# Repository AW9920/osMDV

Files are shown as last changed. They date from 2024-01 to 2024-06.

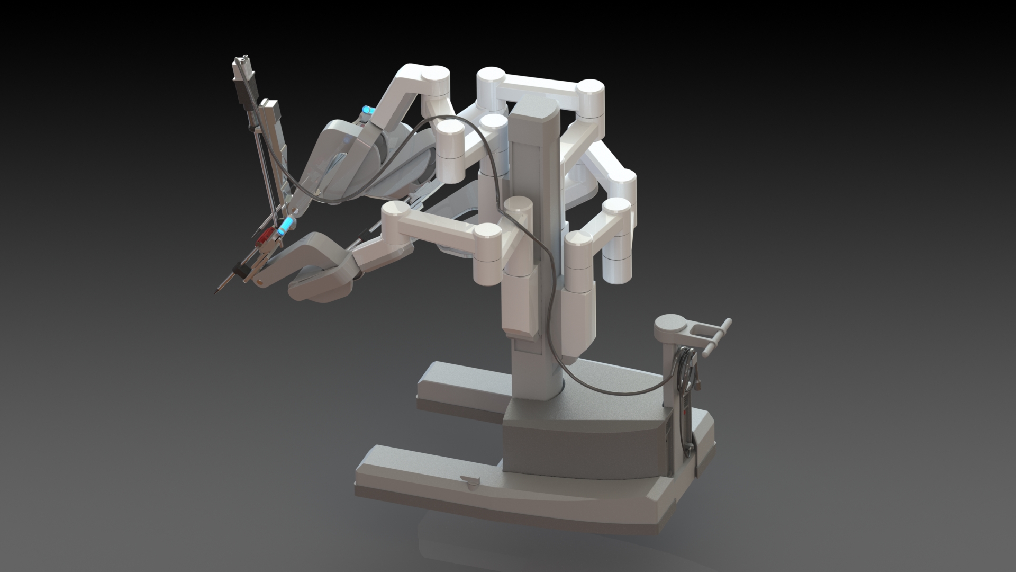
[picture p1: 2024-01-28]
CAD-PSM/Ueberarbeiteter DaVincikopf/da-vinci-surgical-robot-1.snapshot.1/DaVinci/Render/3.JPG

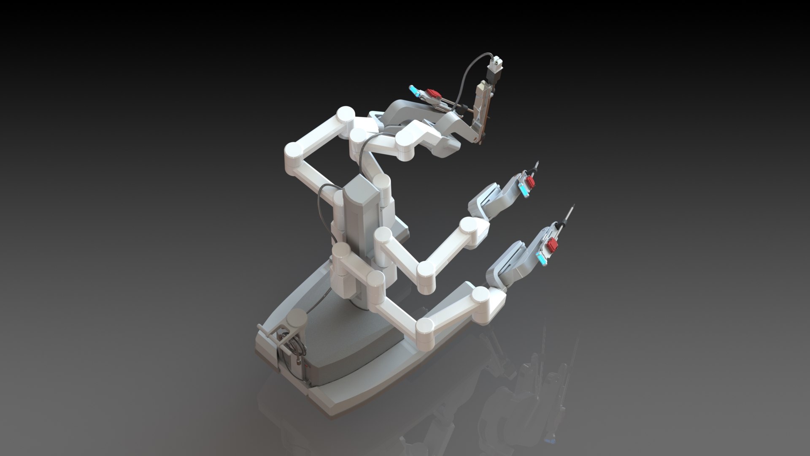
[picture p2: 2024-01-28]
CAD-PSM/Ueberarbeiteter DaVincikopf/da-vinci-surgical-robot-1.snapshot.1/DaVinci/Render/9.JPG

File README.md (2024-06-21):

# Open-Source Desktop Teleoperated Surgical Training System


Welcome to the repository for the **Open-Source Desktop Teleoperated Surgical Training System**. This project provides cost-efficient and accessible resources for a surgical training system.

## Features

- **Master-Tool-Manipulator (MTM)**: A serial link manipulator capable of measuring the operator’s motion in 7 degrees of freedom (DoF), including 3 DoF for hand translation, 3 DoF for wrist rotation, and 1 DoF for grasping motion.
- **Patient-Side-Manipulator (PSM)**: Based on the da Vinci Classic system, this manipulator features a double parallelogram mechanism and is capable of precise motion replication.
- **Kinematic Models**: Detailed kinematic models for both MTM and PSM using the Denavit-Hartenberg (DH) method.
- **Gravity-Compensation-System (GCS)**: Simulated spatial positions of the center of gravity for counterbalancing mechanisms, designed using a least-square fitting algorithm.

## Repository Contents

- **CAD Drawings**: Detailed CAD drawings for the MTM and PSM, including all necessary components and assembly instructions.
- **Source Code**: Control algorithms, kinematic models, and simulation scripts necessary for operating the MTM and PSM.
- **Calculations**: Documentation of the kinematic and dynamic calculations used in the system design.

## License
This project is licensed under the MIT License. See the LICENSE file for more details.

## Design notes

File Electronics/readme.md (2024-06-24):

# Electronics MTM

## General Description of the Electrical Setup MTM
The robotic arm system incorporates sensors and controllers to detect movements and control various joints. Each side of the arm is equipped with sensors for shoulder pitch, shoulder yaw, elbow pitch, wrist, and grip, all centrally controlled by an Arduino Mega.

### Shoulder Pitch Subsystem:
- **Magnetic Encoder (AEAT-6012-A06)**: Provides precise feedback on the shoulder pitch position.

### Shoulder Yaw Subsystem:
- **Magnetic Encoder (AEAT-6012-A06)**: Measures the shoulder yaw angle accurately.

### Elbow Pitch Subsystem:
- **Magnetic Encoder (AEAT-6012-A06)**: Monitors the elbow pitch movement.

### Wrist Subsystem:
- **MPU 6050**: Tracks the wrist orientation and movement. The MPU measures 3 degrees of freedom.

### Grip Subsystem:
- **Hall Sensor**: Detects the grip force or position. The location of the measurement is the grip between index finger and thumb.

### Controller
- **Arduino Mega**: The central controller orchestrates the operations of all subsystems. It processes input signals from the encoders, MPU 6050 sensors, and Hall sensors and sends appropriate control signals to achieve coordinated and precise movements of the robotic arm.

## Electrical Schematic MTM




# Electronics PSM

## General Description of the Electrical Setup
The MTM detects movements in 7 dimensions of freedom. Consequently, the PSM requires 7 motors to replicate these movements. Servo motors, which have integrated position control, are utilized for wrist movements. For the outer yaw, pitch, and insertion, DC motors are employed, and these motors need additional encoders for position control. To calibrate the encoders, the PSM uses limit switches to detect the end positions.

The electrical system of the project is composed of three main subsystems: outer pitch, outer yaw, and insertion. Each subsystem is managed by a central controller, the Teensy 4.1, which interfaces with various sensors, motors, and motor drivers to ensure precise and coordinated movement.

### Outer Pitch Subsystem
- **Limit Switch**: An Omron D2F-L-A1 limit switch is used to detect the end-of-travel positions for safety and calibration purposes.
- **Encoder**: A Broadcom HEDS-5540 encoder provides feedback on the rotational position and speed of the DC motor.
- **DC Motor**: A Maxon 273752 15V DC motor is responsible for generating the necessary torque and motion.
- **Motor Driver**: An MD13S Cytron 13 Amp motor driver controls the power supplied to the DC motor based on commands from the controller.

### Outer Yaw Subsystem
- **Limit Switch**: Another Omron D2F-L-A1 limit switch is employed to detect the limits of travel.
- **Encoder**: The Broadcom HEDS-5540 encoder offers precise feedback on the motor's position and velocity.
- **DC Motor**: A similar Maxon 273752 15V DC motor is used for the yaw movement.
- **Motor Driver**: The MD13S Cytron 13 Amp motor driver modulates the power delivered to the DC motor.

### Insertion Subsystem
- **Limit Switch**: The Omron D2F-L-A1 limit switch is utilized for detecting the extreme positions.
- **Encoder**: The Broadcom HEDS-5540 encoder measures the rotational position for precise control.
- **Servo Motor**: A servo motor (HV7346MG) with position control removed is used to drive the insertion mechanism.
- **Motor Driver**: The same MD13S Cytron 13 Amp motor driver is used to control the servo motor.

### Wrist Subsystem
The wrist subsystem comprises multiple servo motors (MG966r) for fine-tuned multi-axis control. These servos are directly controlled by the Teensy 4.1 controller to achieve the desired movements.

### Controller
- **Teensy 4.1**: The central controller that orchestrates the operations of all subsystems. It processes input signals from encoders and limit switches and sends appropriate control signals to the motor drivers and servo motors.



## Electrical Schematic PSM







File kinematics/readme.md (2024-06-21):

# Kinematic Model - MTM

MTM_Kinematics_v2

## **DH-Parameters of the MTM**

| i | theta_i / rad | d_i / mm | a_i / mm | alpha_i / rad |
|---|---|---|---|---|
| 1 | q_1 | 0 | l_sho | pi/2 |
| 2 | q_2 | 0 | l_arm | -pi/2 |
| 3 | q_3 - pi/2 | -l_ball  | l_arm | -pi/2 |
| 4 | q_4 - pi/2 | 0 | 0 | -pi/2 |
| 5 | q_5 - pi/2 | 0 | 0 | -pi/2 |
| 6 | q_6 + pi/2 | -l_IMU | 0 | -pi/2 |

With geometric parameters being:
l_arm = 217.50 mm
l_ball = 8.70 mm
l_IMU = 37.40 mm

# Kinematic Model - PSM

PSM_Kinematics_v2

##  **DH-Parameters of the PSM**

| i | theta_i / rad |  d_i / mm | a_i / mm | alpha_i / rad |
|---|---|---|---|---|
| 1 | q_1 | 0 | 0 | -pi/2 |
| 2 | q_2 - pi/2 | 0 | 0 | pi/2 |
| 3 | 0 | q_3 - l_RCM | 0 | 0 |
| | 0 | l_tool | 0 | 0 |
| 4 | q_4 | 0 | 0 | -pi/2 |
| 5 | q_5 - pi/2 | 0 | l_P2Y | -pi/2 |
| 6 | q_6 | 0 | l_Y2T | 0 |

With geometric parameters being:
l_RCM   = 456.00 mm
l_P2Y   = 9.00 mm
l_tool  = 432.50 mm
l_Y2T   = 10.10 mm

# Inverse Kinematics Wrist Rotation

The analytical form of 3R6 is derived from the DH parameters of the PSM, whereas the elements of the matrix depicted in
the second equation poses numerical values resulting from the transformation of IMU values in Rotation Matrix form (0R6).

### Matrices

$$
^3R_6 = \begin{bmatrix}
-c_4 c_6 - s_4 s_5 s_6 & -s_4 c_5 & c_4 s_6 + s_4 s_5 c_6 \\
s_4 c_6 + c_4 s_5 s_6 & c_4 c_5 & s_4 s_6 + c_4 s_5 c_6 \\
-c_5 s_6 & s_5 & -c_5 c_6
\end{bmatrix}
$$

$$
^0R_3^{-1} \cdot ^0R_6 = \begin{bmatrix}
r_{11} & r_{12} & r_{13} \\
r_{21} & r_{22} & r_{23} \\
r_{31} & r_{32} & r_{33}
\end{bmatrix}
$$

Based on the detailed notation, it is determined that joint values q4, q5, and q6 can be estimated according to the equations listed below.

$$
 q_4 = \arctan2\left(-\frac{r_{12}}{c_5}, \frac{r_{22}}{c_5}\right) 
$$

$$
q_5 = \arctan2\left(r_{32}, \pm\sqrt{(r_{12})^2 + (r_{22})^2}\right) 
$$

$$
q_6 = \arctan2\left(-\frac{r_{31}}{c_5}, -\frac{r_{33}}{c_5}\right) 
$$

# Interpretation of Disk Rotation

The discs of the surgical instrument must be actuated properly to authentically recreate the previously calculated joint values

##  Correlation Matrix
The transmission rate between the disc number and corresponding joint values are estimated and listed below.





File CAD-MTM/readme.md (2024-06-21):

# CAD of the Master Tool Manipulator

This folder provides mechanical assembly and CAD drawings.

## Overview

This section of the repository focuses on the mechanical aspects of the teleoperated surgical training system, including the Master-Tool-Manipulator (MTM). These components are designed to be affordable and easy to assemble, reducing the entry barrier for research and educational purposes.

## Mechanical Assemblies

The MTM is a serial link manipulator designed to measure the operator's motion in 7 degrees of freedom (DoF), including:

- 3 DoF for hand translation
- 3 DoF for wrist rotation
- 1 DoF for grasping motion

**Components:**

- **Frame**: The main structure supporting the MTM.
- **Joints**: Seven joints allowing for the specified degrees of freedom.
- **Encoders**: Three absolute magnetic encoders (AEAT-6012-A06, Broadcom) for measuring hand translation.
- **IMU**: A 6-axis inertial measurement unit encased in a wrist control unit (WCU) for wrist rotation estimation.
- **Hall Sensor**: A sensor (SS495A1, Honeywell) for grasping motion detection.

Revised_MTM_v2

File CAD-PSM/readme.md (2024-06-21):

# CAD of Patient Side Manipulator

This folder provides mechanical assembly and CAD drawings of the PSM.

## Overview

This section of the repository focuses on the mechanical aspects of the teleoperated surgical training system, including the PSM. These components are designed to be affordable and easy to assemble, reducing the entry barrier for research and educational purposes.
The PSM is based on the DaVinci Classic system and features a double parallelogram mechanism for precise motion replication.

**Components:**

- **Frame**: The main supporting structure for the PSM.
- **Joints**: Seven joints, actuated by DC motors (273752, MAXON).
- **Servo Motors**: Four servo motors (HS-65HB+, Hitec) for wrist movements.
- **Optical Encoders**: Encoders (HEDS-5540#A11, Broadcom) for angular position measurement.
- **Surgical Instrument Mount**: A sled to accommodate surgical instruments.

**DPM Base**
ForkMecha
**DPM**
DPM_v2
**Base Shaft**
AX0_new
**Head Assembly**
Guidance
**Tool Carriage**
Carriage_v2

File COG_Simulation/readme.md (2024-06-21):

# COG Simulation
This section provides MATLAB files to calculate the center of gravity of the PSM and MTM throughout their workspace
## COG Calculation MTM

Based on the following mechanical schematic, the position of the MTM's COG is computed as a function of its joint values q1 to q3  



The COG of each link as a function of its corresponding joint values is given below  

COG locations as function of joint values  

## COG Calculation PSM

The positions of the PSM's COGs are computed as a function of its corresponding joint values  



This COG of each of the 6 links of the PSM are computed as listed below  



The simulation of the total COG of MTM and PSM respectively is based on these considerations.

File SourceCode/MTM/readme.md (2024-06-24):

# General Functionality MTM
For both MTMs of the training console, the program is required to read the data from a total of six absolute magnetic encoders, two IMUs and two Hall effect sensors. Whereas, for the received data, a distinction must be made between the movement data of the left and right arm. This results in a total of eight sensor values received per MTM which must be communicated to the computer I/O where they are processed into appropriate joint values for the PSM. 

## MT_MTM.ino
The main control file for the MTM system.
- Integrating all subsystems and coordinating their operations.
- Handling communication with the central controller (Arduino Mega).
- Managing the overall workflow of the MTM system.

### spikeDetection.ino
This file handles the detection of spikes in the movement data, which might indicate rapid or sudden movements. Key functionalities include:
- Variables to store previous and current IMU (Inertial Measurement Unit) readings.
- Spike detection logic to identify abrupt changes in movement.
- Implementation of counters and difference calculations to process the movement data.

### Initial_preVal_def.ino
This file initializes various variables and sets up default values for the system. Key functionalities include:
- Defining initial positions and orientations for the robot.
- Setting up initial encoder values and IMU addresses.
- Initializing kinematic variables for both MTM and PSM.

### KinematicCalc_L.ino and KinematicCalc_R.ino
These files perform kinematic calculations for the left and right sides of the robot, respectively. Key functionalities include:
- Calculating joint angles and positions based on encoder and IMU data.
- Updating the kinematic chain for the MTM to ensure accurate movement detection.

### LPFilter.ino and LPFilter_Encoder.ino
These files implement low-pass filters to smooth the data received from the sensors. Key functionalities include:
- Filtering IMU data to remove noise and ensure smooth movement detection.
- Filtering encoder data to ensure accurate position readings.

### readEncoder.ino
This file contains the code to read data from the encoders. Key functionalities include:
- Reading the position data from the encoders connected to the robot joints.
- Processing the encoder signals to extract meaningful position information.

### OverFlowDetection.ino
This file handles the detection of overflow conditions in the sensor data. Key functionalities include:
- Monitoring sensor values to detect overflows.
- Implementing corrective actions to handle overflow conditions and ensure continuous operation.

### readIMU.ino
This file contains the code to read data from the IMUs. Key functionalities include:
- Reading quaternion data from the IMUs to determine the orientation of the robot.
- Handling FIFO (First In, First Out) buffers to manage IMU data efficiently.

### setupIMU.ino
This file sets up the IMUs (Inertial Measurement Units) for use in the MTM system. Key functionalities include:
- Initializing IMU sensors.
- Configuring IMU settings and calibration parameters.
- Ensuring the IMUs are ready for accurate orientation tracking.

### parseData.ino
This file contains the logic to parse incoming data strings. Key functionalities include:
- Tokenizing received data strings.
- Converting tokenized strings into numerical values.
- Storing parsed data into appropriate variables for further processing.

### recvWithStartEndMarkers.ino
This file implements the functionality to receive data with defined start and end markers. Key functionalities include:
- Detecting start and end markers in incoming serial data.
- Extracting and storing data between the markers.
- Setting flags to indicate new data availability for processing.

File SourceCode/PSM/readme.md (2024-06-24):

# General Functionality
The PSM code is designed to accurately replicate the movements detected by the MTM. It does so by receiving movement data from the MTM, parsing and processing this data, and then using it to control the PSM's motors and servos. The system uses PID control to ensure precise movements and implements various safety and efficiency measures such as ramp-up routines, collision detection, and low-pass filtering.

## MT_PSM.ino
This is the main control file for the PSM system. Key functionalities include:
- Initializing the PSM components and setting up initial configurations.
- Reading data from the MTM and converting it into commands for the PSM.
- Handling the overall workflow (see the following picture) of the PSM to ensure it accurately replicates MTM movements.

  

## parseData.ino
This file contains the logic to parse incoming data strings from the MTM. Key functionalities include:
- Tokenizing received data strings.
- Converting tokenized strings into numerical values.
- Storing parsed data into appropriate variables for further processing.

## PIDupdate.ino
This file implements PID (Proportional-Integral-Derivative) control for the motors. Key functionalities include:
- Calculating PID values to control motor speed and position.
- Adjusting motor commands based on the PID calculations to ensure precise movements.

## PosSampler.ino
This file handles the sampling of position data. Key functionalities include:
- Reading position data from sensors.
- Storing sampled data for use in control algorithms.
- Ensuring that position data is accurately and consistently captured.

## RampUp_Homing.ino
This file implements ramp-up and homing routines for the PSM. Key functionalities include:
- Performing homing sequences to establish a known starting position for the PSM.

## recvWithStartEndMarkers.ino
This file handles the reception of data with defined start and end markers. Key functionalities include:
- Detecting start and end markers in incoming serial data.
- Extracting and storing data between the markers.
- Setting flags to indicate new data availability for processing.

## setPwmFrequency.ino
This file sets the PWM (Pulse Width Modulation) frequency for the motors. Key functionalities include:
- Configuring PWM settings for motor control.
- Ensuring that motors operate at the correct frequency for smooth and precise movements.

## Catch_Tool.ino
This file contains routines to catch and manipulate tools. Key functionalities include:
- Controlling servos to grip the tool securely.
- Returning to the initial position after catching the tool.

## CheckCol.ino
This file checks for collision conditions during operation. Key functionalities include:
- Monitoring limit switches to detect collisions.
- Stopping motors if a collision is detected to prevent damage.
- Ensuring safe operation by avoiding excessive forces.

## LPFilter_DT.ino
This file implements a low-pass filter for delta time signals. Key functionalities include:
- Filtering delta time measurements to remove noise.
- Ensuring stable and accurate time measurements for control algorithms.

# Referencing
Since incremental encoders are utilized for joint axis 1, 2, and 3, the system must conduct a reference drive before it is ready for operation. This is necessary since the encoders do not possess an absolute point of reference, which causes a loss of position whenever the program execution is terminated. Therefore, a state machine is implemented to guide each joint towards a limit switch positioned at a specific angle. Since the encoders of the remaining joints are able to measure the absolute position at any time, they are excluded from the reference drive procedure. The protocol of the state machine is visualized by the flow chart in Figure.



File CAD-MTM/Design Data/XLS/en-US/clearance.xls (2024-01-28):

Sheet: Ansi Unified Screw Threads
I | Sort Order -1
Fastener Type | Size | Shaft Diameters |  |  | Head Dimensions
 |  | Close | Normal | Loose | Diameter | Depth/Angle | Head Type
Flat Head Machine Screw (82) | #0 | 0.0635 | 0.07 | 0.073 | 0.119 | 82 | 2
Flat Head Machine Screw (82) | #1 | 0.076 | 0.081 | 0.089 | 0.146 | 82 | 2
Flat Head Machine Screw (82) | #2 | 0.089 | 0.096 | 0.1065 | 0.172 | 82 | 2
Flat Head Machine Screw (82) | #3 | 0.104 | 0.11 | 0.12 | 0.199 | 82 | 2
Flat Head Machine Screw (82) | #4 | 0.116 | 0.1285 | 0.136 | 0.225 | 82 | 2
Flat Head Machine Screw (82) | #5 | 0.1285 | 0.136 | 0.154 | 0.252 | 82 | 2
Flat Head Machine Screw (82) | #6 | 0.144 | 0.1495 | 0.1695 | 0.279 | 82 | 2
Flat Head Machine Screw (82) | #8 | 0.1695 | 0.177 | 0.1935 | 0.332 | 82 | 2
Flat Head Machine Screw (82) | #10 | 0.196 | 0.201 | 0.221 | 0.385 | 82 | 2
Flat Head Machine Screw (82) | #12 | 0.221 | 0.228 | 0.246 | 0.438 | 82 | 2
Flat Head Machine Screw (82) | 1/4 | 0.257 | 0.266 | 0.2812 | 0.507 | 82 | 2
Flat Head Machine Screw (82) | 5/16 | 0.323 | 0.332 | 0.3437 | 0.635 | 82 | 2
Flat Head Machine Screw (82) | 3/8 | 0.386 | 0.397 | 0.4062 | 0.762 | 82 | 2
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

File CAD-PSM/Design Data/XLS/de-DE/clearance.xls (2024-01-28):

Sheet: ANSI UST
I | Reihenfolge -1
Schraubentyp | Größe | Wellendurchmesser |  |  | Schraubenkopfbemaßungen
 |  | Schließen | Normal | Grob | Durchmesser | Tiefe/Winkel | Schraubenkopftyp
Flachkopfmaschinenschraube (82) | #0 | 0.0635 | 0.07 | 0.073 | 0.119 | 82 | 2
Flachkopfmaschinenschraube (82) | #1 | 0.076 | 0.081 | 0.089 | 0.146 | 82 | 2
Flachkopfmaschinenschraube (82) | #2 | 0.089 | 0.096 | 0.1065 | 0.172 | 82 | 2
Flachkopfmaschinenschraube (82) | #3 | 0.104 | 0.11 | 0.12 | 0.199 | 82 | 2
Flachkopfmaschinenschraube (82) | #4 | 0.116 | 0.1285 | 0.136 | 0.225 | 82 | 2
Flachkopfmaschinenschraube (82) | #5 | 0.1285 | 0.136 | 0.154 | 0.252 | 82 | 2
Flachkopfmaschinenschraube (82) | #6 | 0.144 | 0.1495 | 0.1695 | 0.279 | 82 | 2
Flachkopfmaschinenschraube (82) | #8 | 0.1695 | 0.177 | 0.1935 | 0.332 | 82 | 2
Flachkopfmaschinenschraube (82) | #10 | 0.196 | 0.201 | 0.221 | 0.385 | 82 | 2
Flachkopfmaschinenschraube (82) | #12 | 0.221 | 0.228 | 0.246 | 0.438 | 82 | 2
Flachkopfmaschinenschraube (82) | 1/4 | 0.257 | 0.266 | 0.2812 | 0.507 | 82 | 2
Flachkopfmaschinenschraube (82) | 5/16 | 0.323 | 0.332 | 0.3437 | 0.635 | 82 | 2
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

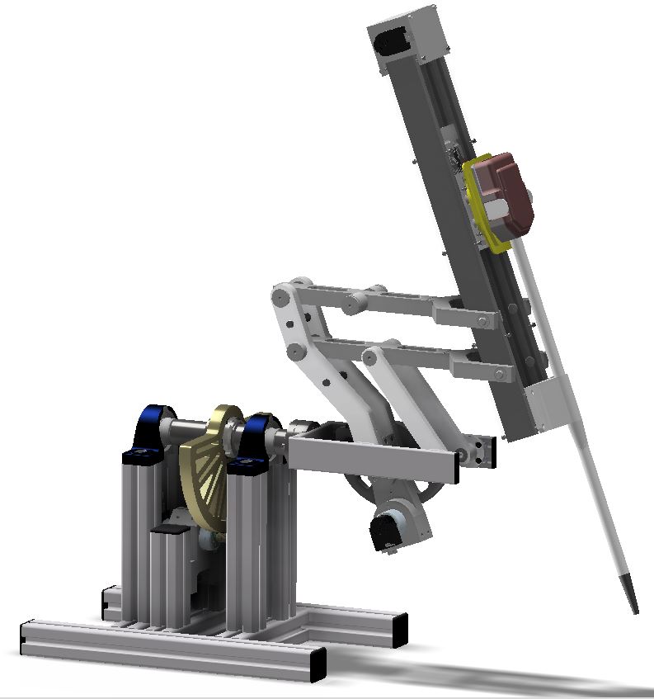
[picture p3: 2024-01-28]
CAD-PSM/RenderedImages/PSM_Unrendered.JPG

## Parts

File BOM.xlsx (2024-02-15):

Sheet: PSM
Buy | Product Name | Anz. | VPE | Part Number | Unit Price | Total Price
 | CONRAD
x | 10294 Sicherungsringe-Sortiment Inhalt 240 Teile | 1 | Pkg | 10294 | 15.99 € | 15.99 €
x | FAG KM8 Nutmutter Bohrungs-Ø 40 mm Außen-Durchmesser 58 mm | 1 | Stk | KM8 | 12.99 € | 12.99 €
x | TOOLCRAFT 1060910 Sicherungsringe Innen-Durchmesser: 27.9 mm DIN 471 Edelstahl 25 St. | 1 | Pkg | 1060910 | 47.99 € | 47.99 €
x | Amewi Standard-Servo HV7346MG Digital-Servo | 1 | Stk | 28968 | 69.99 € | 69.99 €
 | KUGELLAGER EXPRESS
x | Edelstahl Miniatur Kugellager SS MR128 W2.5 offen geölt 8x12x2.5 mm | 10 | Stk | SS-MR-128-W2.5-OIL | 1.99 € | 19.90 €
x | Edelstahl Miniatur Kugellager SS MR63 W2 offen geölt 3x6x2 mm | 10 | Stk | SS-MR-63-W2-OIL | 2.17 € | 21.70 €
x | ITEM Profile_8 40x40 L=2m | 4 | Stk | 761-3319 | 34.31 € | 137.24 €
x | Rillenkugellager 6800 / 61800 2RS 10x19x5 mm | 10 | Stk | 6800-2RS | 0.89 € | 8.90 €
x | Rillenkugellager 6900 / 61900 2RS 10x22x6 mm | 10 | Stk | 6900-2RS | 1.06 € | 10.60 €
x | Rillenkugellager 6700 / 61700 2RS 10x15x4 mm | 10 | Stk | 6700-2RS | 0.99 € | 9.90 €
x | Miniatur Kugellager 628 2RS 8x24x8 mm | 10 | Stk | 628-2RS | 0.65 € | 6.50 €
x | Stehlagereinheit UCP204 | 2 | Stk | UCP204 | 7.00 € | 14.00 €
 | RS COMPONENTS
x | ZF Mikroschalter Kurzer Hebel-Betätiger, Einpoliger Wechselschalter, 6 A @ 250 V ac | 10 | Stk | DB1C-A1LB | 3.31 € | 33.10 €
x | RS PRO Sicherungsringe Aussenring für Wellen-Ø 8mm, Nut-Ø 7.6mm 0.8mm 14.7mm Edelstahl | 1 | Pkg | 209-6615 | 15.71 € | 15.71 €
x | Gewindeeinsatzwerkzeug, enthält Dorn & Mundstücke, Einsatzgröße: M6 - M3 | 1 | Stk | 487-151 | 43.83 € | 43.83 €
x | RS PRO Sicherungsmuttern, Stahl Glatt, M40 9mm | 2 | Stk | 196-4174 | 6.73 € | 13.46 €
x | RS PRO Blind Niet, Ø 7.1mm x 12mm, Grau, Stahl, M5, 7.2mm, min. 0.5mm, max. 2.5mm | 1 | Pkg | 206-5530 | 7.13 € | 7.13 €
x | RS PRO Serie 2 Alu Strebenprofil 40 x 16 mm, 1-fach Nut 8mm, Länge 3000mm | 1 | Stk | 187-3278 | 45.52 € | 45.52 €
x | T-Slot Nut 8 St M6 | 2 | VPE | 4016212 | 22.82 € | 45.64 €
 | maxon | Kwapil & Co
x | DC-Motor - RE35 GB 90W KL 2WE | 2 | Stk | 273752 | 286.25 | 572.50 €
 | Modellbau Lindinger GmbH
x | HITEC HS-65HB (6V/2KG/0,11s) Analog Mini Servo | 4 | Stk | 112065 | 24.99 | 99.96 €
 | Mouser
x | Motor driver Cytron MD13S | 3 | Stk | 108070021 | 13.90 € | 41.70 €
x | Teensy 4.1, mit Ethernet, ohne Header | 1 | Stk | DEV-16771 | 38.00 € | 38.00 €
x | Optical Encoder HEDS-5540#A11 | 3 | Stk | HEDS-5540#A11 | 52.93 € | 158.79 €
 | MISUMI
x | DIN 2093 Tellerfedern Di10.2 Do20 | 1 | Pkg | 20930000201008 | 24.00 € | 24.00 €
x | DIN 137 Federscheiben Do12 | 1 | Pkg | 1370029120000 | 15.00 € | 15.00 €
x | iglidur® W300, Anlaufscheibe | 4 | Stk | WTM-1426-015 | 5.28 € | 21.12 €
x | iglidur® W300, Anlaufscheibe | 10 | Stk | WTM-1018-010 | 2.23 € | 22.30 €
x | iglidur® W300, Anlaufscheibe | 10 | Stk | WTM-1224-015 | 2.39 € | 23.90 €
x | Gleitlagerbuchsen / mit Bund / POM | 10 | Stk | JZF10-6 | 0.46 € | 4.60 €
 | MISC
x | Materialkosten | 1 |  |  | 30.00 € | 30.00 €
 |  |  |  |  | Total: | 1631.96 €

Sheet: MTM
Product Name | Anz. | VPE | Part Number | Unit Price | Total Price
ALBERTS by EXPERT-Security
Rundrohr Aluminium silber eloxiert 12x1/1m | 2 | Stk | 10013526 | 1.98 € | 3.96 €
Rundrohr Aluminium silber eloxiert 10x1/1m | 2 | Stk | 10013525 | 2.02 € | 4.04 €
RS COMPONENTS
Broadcom Servo-Potenziometer Absolutgeber, mit 6 mm, Glattschaft, Schaft L. 8.5mm | 6 | Stk | AEAT-6012-A06 | 35.53 | 213.18
ITEM Profile_8 40x40 L=1m | 1 | Stk | 761-3319 | 34.31 | 34.31
Reichelt Elektronik
Entwicklerboards - Beschleunigung & Gyroskop, 3-Achsen, MPU-6050 | 2 | Stk | DEBO SENS 3AXIS | 6.55 | 13.1
Teensy 4.1, mit Ethernet, ohne Header | 1 | Stk | DEV-16771 | 37.99 | 37.99
KUGELLAGER EXPRESS
Rillenkugellager 6700 / 61700 2RS 10x15x4 mm | 4 | Stk | 6700-2RS | 1.02 | 4.08
Kegelrollenlager 32005 X 25x47x15 mm | 2 | Stk | 32005-X | 4.03 | 8.06
Edelstahl Miniatur Kugellager SS MR63 W2 offen geölt 3x6x2 mm | 10 | Stk | SS-MR-63-W2-OIL | 2.17 € | 21.70 €
 |  |  |  | Total: | 336.46 €

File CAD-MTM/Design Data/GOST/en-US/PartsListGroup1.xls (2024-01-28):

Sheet: Лист 1
Инв. № подл |  |  |  | Подп. и дата | Взам. инв. № | Инв. № дубл. |  |  | Подп. и дата
Формат | Зона | Поз. | Обозначение |  |  |  | Наименование |  |  |  |  |  | Кол. на исполнение
 |  |  |  |  |  |  |  |  |  |  |  | Лит.
 |  |  |  |  |  |  |  |  |  |  |  | Код
 |  |  |  |  |  |  |  | Изм. | Лист | № докум | Подпись |  | Дата
 |  |  |  |  |  |  |  | Разраб.
 |  |  |  |  |  |  |  | Пров.
 |  |  |  |  |  |  |  | Н.контр
 |  |  |  |  |  |  |  | Утв.
 |  |  |  |  |  |  |  |  |  |  |  |  |  | Копировал

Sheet: Лист 2
Инв. № подл |  |  |  | Подп. и дата | Взам. инв. № | Инв. № дубл. |  |  | Подп. и дата
Формат | Зона | Поз. | Обозначение |  |  |  | Наименование |  |  |  |  | Кол. на исполнение
 |  |  |  |  |  |  |  | Изм. | Лист | № докум. | Подп. | Дата
 |  |  |  |  |  |  |  |  |  |  |  |  | Копировал
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

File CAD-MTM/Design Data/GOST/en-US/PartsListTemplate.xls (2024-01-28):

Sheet: Лист 1
 | Формат | Зона |  | Поз. |  | Обозначение |  |  |  | Наименование |  |  |  | Кол. | Приме-чание
Подп. и дата
Инв. № дубл.
Взам. инв. №
Подп. и дата
 | Изм. |  | Лист |  | № докум |  | Подпись | Дата
Инв. № подл | Разраб. |  |  |  |  |  |  |  |  |  | Литера |  | Лист |  |  | Листов
 | Пров.
 | Н.контр
 | Утв.
 |  |  |  |  |  |  |  |  | Копировал |  |  | Формат А4

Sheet: Лист 2
 | Формат | Зона |  | Поз. |  | Обозначение |  |  |  | Наименование |  | Кол. | Приме-чание
Подп. и дата
Инв. № дубл.
Взам. инв. №
Подп. и дата
Инв. № подл
 | Изм. |  | Лист |  | № докум. |  | Подп. |  | Дата
 |  |  |  |  |  |  |  | Копировал |  |  | Формат А4
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

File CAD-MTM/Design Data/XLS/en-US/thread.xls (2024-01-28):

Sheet: Inch Tapping Threads
I Q X | Inch Tapping Threads |  | Sort Order - 5 |  | External |  |  |  |  |  |  | Internal
 |  |  |  |  |  | Major Dia |  | Pitch Dia |  | Minor Dia |  |  | Minor Dia |  | Pitch Dia |  | Major Dia |  | Tap Drill
Size | Size Suffix | Thread Designation | Custom Thread Designation | TPI | Class | Max | Min | Max | Min | Max | Min | Class | Min | Max | Min | Max | Min | Max | Basic
0.0600 |  | 0-48 | 0-48 | 48 | 2B | 0.0600 | 0.0540 | 0.0480 | 0.0435 | 0.0360 | 0.0330
0.0730 |  | 1-42 | 1-42 | 42 | 2B | 0.0750 | 0.0690 | 0.0620 | 0.0575 | 0.0490 | 0.0460
0.0860 |  | 2-32 | 2-32 | 32 | 2B | 0.0880 | 0.0820 | 0.0760 | 0.0710 | 0.0640 | 0.0600
0.0990 |  | 3-28 | 3-28 | 28 | 2B | 0.1010 | 0.0950 | 0.0880 | 0.0830 | 0.0750 | 0.0710
0.1120 |  | 4-24 | 4-24 | 24 | 2B | 0.1140 | 0.1080 | 0.1000 | 0.0950 | 0.0860 | 0.0820
0.1250 |  | 5-20 | 5-20 | 20 | 2B | 0.1300 | 0.1230 | 0.1120 | 0.1065 | 0.0940 | 0.0900
0.1380 |  | 6-20 | 6-20 | 20 | 2B | 0.1390 | 0.1320 | 0.1215 | 0.1155 | 0.1040 | 0.0990
0.1510 |  | 7-19 | 7-19 | 19 | 2B | 0.1540 | 0.1470 | 0.1345 | 0.1280 | 0.1150 | 0.1090
0.1640 |  | 8-18 | 8-18 | 18 | 2B | 0.1660 | 0.1590 | 0.1440 | 0.1375 | 0.1220 | 0.1160
0.1900 |  | 10-16 | 10-16 | 16 | 2B | 0.1890 | 0.1820 | 0.1650 | 0.1585 | 0.1410 | 0.1350
0.2160 |  | 12-14 | 12-14 | 14 | 2B | 0.2150 | 0.2080 | 0.1895 | 0.1825 | 0.1640 | 0.1570
0.2420 |  | 14-14 | 14-14 | 14 | 2B | 0.2410 | 0.2340 | 0.2130 | 0.2060 | 0.1850 | 0.1780
0.2500 |  | 1/4-14 | 1/4-14 | 14 | 2B | 0.2460 | 0.2370 | 0.2190 | 0.2110 | 0.1920 | 0.1850
0.3125 |  | 5/16-12 | 5/16-12 | 12 | 2B | 0.3150 | 0.3060 | 0.2795 | 0.2710 | 0.2440 | 0.2360
0.3750 |  | 3/8-12 | 3/8-12 | 12 | 2B | 0.3800 | 0.3710 | 0.3445 | 0.3350 | 0.3090 | 0.2990
0.4375 |  | 7/16-10 | 7/16-10 | 10 | 2B | 0.4400 | 0.4290 | 0.3995 | 0.3890 | 0.3590 | 0.3490
0.5000 |  | 1/2-10 | 1/2-10 | 10 | 2B | 0.5040 | 0.4930 | 0.4635 | 0.4530 | 0.4230 | 0.4130

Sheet: Metric Forming Screw Threads
M P X | Metric Forming Screw Threads |  | Sort Order - 6 |  | External |  |  |  |  |  |  | Internal
 |  |  |  |  |  | Major Dia |  | Pitch Dia |  | Minor Dia |  |  | Minor Dia |  | Pitch Dia |  | Major Dia |  | Tap Drill
Size | Size Suffix | Thread Designation | Custom Thread Designation | Pitch | Class | Max | Min | Max | Min | Max | Min | Class | Min | Max | Min | Max | Min | Max | Basic
1.5 |  | 1.5x0.5 | 1.5x0.5 | 0.5 | 6g | 1.520 | 1.380 | 1.215 | 1.110 | 0.910 | 0.840
1.5 |  | ST1.5x0.5 | ST1.5x0.5 | 0.5 | 6g | 1.520 | 1.380 | 1.215 | 1.110 | 0.910 | 0.840
1.9 |  | 1.9x0.6 | 1.9x0.6 | 0.6 | 6g | 1.900 | 1.760 | 1.570 | 1.465 | 1.240 | 1.170
1.9 |  | ST1.9x0.6 | ST1.9x0.6 | 0.6 | 6g | 1.900 | 1.760 | 1.570 | 1.465 | 1.240 | 1.170
2.2 |  | 2.2x0.8 | 2.2x0.8 | 0.8 | 6g | 2.240 | 2.100 | 1.935 | 1.810 | 1.630 | 1.520
2.2 |  | ST2.2x0.8 | ST2.2x0.8 | 0.8 | 6g | 2.240 | 2.100 | 1.935 | 1.810 | 1.630 | 1.520
2.6 |  | 2.6x0.9 | 2.6x0.9 | 0.9 | 6g | 2.570 | 2.430 | 2.235 | 2.115 | 1.900 | 1.800
2.6 |  | ST2.6x0.9 | ST2.6x0.9 | 0.9 | 6g | 2.570 | 2.430 | 2.235 | 2.115 | 1.900 | 1.800
2.9 |  | 2.9x1 | 2.9x1 | 1 | 6g | 2.900 | 2.760 | 2.540 | 2.420 | 2.180 | 2.080
2.9 |  | 2.9x1.1 | 2.9x1.1 | 1.1 | 6g | 2.900 | 2.760 | 2.540 | 2.420 | 2.180 | 2.080
2.9 |  | ST2.9x1.1 | ST2.9x1.1 | 1.1 | 6g | 2.900 | 2.760 | 2.540 | 2.420 | 2.180 | 2.080
2.9 |  | 2.9x1.3 | 2.9x1.3 | 1.3 | 6g | 2.900 | 2.720 | 2.540 | 2.355 | 1.890 | 1.700
2.9 |  | 2.9x1.4 | 2.9x1.4 | 1.4 | 6g | 2.900 | 2.720 | 2.340 | 2.175 | 1.780 | 1.630
3.3 |  | 3.3x1.3 | 3.3x1.3 | 1.3 | 6g | 3.300 | 3.120 | 2.795 | 2.665 | 2.290 | 2.210
3.3 |  | ST3.3x1.3 | ST3.3x1.3 | 1.3 | 6g | 3.300 | 3.120 | 2.795 | 2.665 | 2.290 | 2.210
3.5 |  | 3.5x1.3 | 3.5x1.3 | 1.3 | 6g | 3.530 | 3.350 | 3.085 | 2.930 | 2.640 | 2.510
3.5 |  | ST3.5x1.3 | ST3.5x1.3 | 1.3 | 6g | 3.530 | 3.350 | 3.085 | 2.930 | 2.640 | 2.510
3.5 |  | 3.5x1.6 | 3.5x1.6 | 1.6 | 6g | 3.530 | 3.350 | 2.920 | 2.755 | 2.310 | 2.160
3.5 |  | 3.5x3.2 | 3.5x3.2 | 3.2 | 6g | 3.530 | 3.310 | 2.800 | 2.600 | 2.070 | 1.890
3.9 |  | 3.9x1.3 | 3.9x1.3 | 1.3 | 6g | 3.910 | 3.730 | 3.415 | 3.250 | 2.920 | 2.770
3.9 |  | ST3.9x1.3 | ST3.9x1.3 | 1.3 | 6g | 3.910 | 3.730 | 3.415 | 3.250 | 2.920 | 2.770
3.9 |  | 3.9x1.6 | 3.9x1.6 | 1.6 | 6g | 3.910 | 3.730 | 3.300 | 3.135 | 2.690 | 2.540
3.9 |  | 3.9x3.2 | 3.9x3.2 | 3.2 | 6g | 3.910 | 3.690 | 3.180 | 2.980 | 2.450 | 2.270
4.2 |  | 4.2x1.4 | 4.2x1.4 | 1.4 | 6g | 4.220 | 4.040 | 3.660 | 3.495 | 3.100 | 2.950
4.2 |  | ST4.2x1.4 | ST4.2x1.4 | 1.4 | 6g | 4.220 | 4.040 | 3.660 | 3.495 | 3.100 | 2.950
4.2 |  | 4.2x1.6 | 4.2x1.6 | 1.6 | 6g | 4.220 | 4.040 | 3.610 | 3.445 | 3.000 | 2.850
4.2 |  | 4.2x3.2 | 4.2x3.2 | 3.2 | 6g | 4.220 | 4.000 | 3.380 | 3.180 | 2.540 | 2.360
4.8 |  | 4.8x1.6 | 4.8x1.6 | 1.6 | 6g | 4.800 | 4.620 | 4.190 | 4.025 | 3.580 | 3.430
4.8 |  | ST4.8x1.6 | ST4.8x1.6 | 1.6 | 6g | 4.800 | 4.620 | 4.190 | 4.025 | 3.580 | 3.430
4.8 |  | 4.8x1.8 | 4.8x1.8 | 1.8 | 6g | 4.800 | 4.620 | 4.065 | 3.885 | 3.330 | 3.150
4.8 |  | 4.8x3.2 | 4.8x3.2 | 3.2 | 6g | 4.800 | 4.580 | 3.960 | 3.760 | 3.120 | 2.940
5.5 |  | 5.5x1.8 | 5.5x1.8 | 1.8 | 6g | 5.460 | 5.280 | 4.815 | 4.635 | 4.170 | 3.990
5.5 |  | ST5.5x1.8 | ST5.5x1.8 | 1.8 | 6g | 5.460 | 5.280 | 4.815 | 4.635 | 4.170 | 3.990
6.3 |  | 6.3x1.8 | 6.3x1.8 | 1.8 | 6g | 6.250 | 6.030 | 5.565 | 5.365 | 4.880 | 4.700
6.3 |  | ST6.3x1.8 | ST6.3x1.8 | 1.8 | 6g | 6.250 | 6.030 | 5.565 | 5.365 | 4.880 | 4.700
8.0 |  | 8x2.1 | 8x2.1 | 2.1 | 6g | 8.000 | 7.780 | 7.100 | 6.885 | 6.200 | 5.990
8.0 |  | ST8x2.1 | ST8x2.1 | 2.1 | 6g | 8.000 | 7.780 | 7.100 | 6.885 | 6.200 | 5.990
9.5 |  | 9.5x2.1 | 9.5x2.1 | 2.1 | 6g | 9.650 | 9.430 | 8.750 | 8.510 | 7.850 | 7.590
9.5 |  | ST9.5x2.1 | ST9.5x2.1 | 2.1 | 6g | 9.650 | 9.430 | 8.750 | 8.510 | 7.850 | 7.590

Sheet: ISO Pipe Threads
M Q | ISO Pipe Threads |  | Sort Order - 9 |  | External |  |  |  |  |  |  | Internal
 |  |  |  |  |  | Major Dia |  | Pitch Dia |  | Minor Dia |  |  | Minor Dia |  | Pitch Dia |  | Major Dia |  | Tap Drill | Thread Depth | Thread Runouts
Size | Size Suffix | Thread Designation | Custom Thread Designation | TPI | Class | Max | Min | Max | Min | Max | Min | Class | Min | Max | Min | Max | Min | Max | Basic
7.723 |  | G7.723x0.907 | G 1/16 | 28 | A | 7.723 | 7.509 | 7.142 | 7.035 | 6.561 |  |  | 6.561 | 6.834 | 7.142 | 7.249 | 7.723 |  | 1.5875 | 15.446 | 4.5000
7.723 |  | G7.723x0.907 | G 1/16 | 28 | B | 7.723 | 7.509 | 7.142 | 6.928 | 6.561
9.728 |  | G9.728x0.907 | G 1/8 | 28 | A | 9.728 | 9.514 | 9.147 | 9.040 | 8.566 |  |  | 8.566 | 8.848 | 9.147 | 9.254 | 9.728 |  | 3.1750 | 19.456 | 4.5000
9.728 |  | G9.728x0.907 | G 1/8 | 28 | B | 9.728 | 9.514 | 9.147 | 8.933 | 8.566
13.157 |  | G13.157x1.337 | G 1/4 | 19 | A | 13.157 | 12.907 | 12.301 | 12.176 | 11.445 |  |  | 11.445 | 11.89 | 12.301 | 12.426 | 13.157 |  | 6.3500 | 26.314 | 6.5000
13.157 |  | G13.157x1.337 | G 1/4 | 19 | B | 13.157 | 12.907 | 12.301 | 12.051 | 11.445
16.662 |  | G16.662x1.337 | G 3/8 | 19 | A | 16.662 | 16.412 | 15.806 | 15.681 | 14.950 |  |  | 14.95 | 15.395 | 15.806 | 15.931 | 16.662 |  | 9.5250 | 33.324 | 6.5000
16.662 |  | G16.662x1.337 | G 3/8 | 19 | B | 16.662 | 16.412 | 15.806 | 15.556 | 14.950
20.955 |  | G20.955x1.814 | G 1/2 | 14 | A | 20.955 | 20.671 | 19.793 | 19.651 | 18.631 |  |  | 18.631 | 19.172 | 19.793 | 19.935 | 20.955 |  | 12.7000 | 41.910 | 8.5000
20.955 |  | G20.955x1.814 | G 1/2 | 14 | B | 20.955 | 20.671 | 19.793 | 19.509 | 18.631
22.911 |  | G22.911x1.814 | G 5/8 | 14 | A | 22.911 | 22.627 | 21.749 | 21.607 | 20.587 |  |  | 20.587 | 21.128 | 21.749 | 21.891 | 22.911 |  |  | 45.822 | 8.5000
22.911 |  | G22.911x1.814 | G 5/8 | 14 | B | 22.911 | 22.627 | 21.749 | 21.465 | 20.587
26.441 |  | G26.441x1.814 | G 3/4 | 14 | A | 26.441 | 26.157 | 25.279 | 25.137 | 24.117 |  |  | 24.117 | 24.658 | 25.279 | 25.421 | 26.441 |  | 15.8750 | 52.882 | 8.5000
26.441 |  | G26.441x1.814 | G 3/4 | 14 | B | 26.441 | 26.157 | 25.279 | 24.995 | 24.117
30.201 |  | G30.201x1.814 | G 7/8 | 14 | A | 30.201 | 29.917 | 29.039 | 28.897 | 27.877 |  |  | 27.877 | 28.418 | 29.039 | 29.181 | 30.201 |  | 22.2250 | 60.402 | 8.5000
30.201 |  | G30.201x1.814 | G 7/8 | 14 | B | 30.201 | 29.917 | 29.039 | 28.755 | 27.877
33.249 |  | G33.249x2.309 | G 1 | 11 | A | 33.249 | 32.889 | 31.770 | 31.590 | 30.291 |  |  | 30.291 | 30.931 | 31.77 | 31.95 | 33.249 |  | 25.4000 | 66.498 | 10.0000
33.249 |  | G33.249x2.309 | G 1 | 11 | B | 33.249 | 32.889 | 31.770 | 31.410 | 30.291
37.897 |  | G37.897x2.309 | G 1 1/8 | 11 | A | 37.897 | 37.537 | 36.418 | 36.238 | 34.939 |  |  | 34.939 | 35.579 | 36.418 | 36.598 | 37.897 |  | 28.5750 | 75.794 | 10.0000
37.897 |  | G37.897x2.309 | G 1 1/8 | 11 | B | 37.897 | 37.537 | 36.418 | 36.058 | 34.939
41.910 |  | G41.91x2.309 | G 1 1/4 | 11 | A | 41.910 | 41.550 | 40.431 | 40.251 | 38.952 |  |  | 38.952 | 39.592 | 40.431 | 40.611 | 41.910 |  | 31.7500 | 83.820 | 10.0000
41.910 |  | G41.91x2.309 | G 1 1/4 | 11 | B | 41.910 | 41.550 | 40.431 | 40.071 | 38.952
47.803 |  | G47.803x2.309 | G 1 1/2 | 11 | A | 47.803 | 47.443 | 46.324 | 46.144 | 44.845 |  |  | 44.845 | 45.485 | 46.324 | 46.504 | 47.803 |  | 38.1000 | 95.606 | 10.0000
47.803 |  | G47.803x2.309 | G 1 1/2 | 11 | B | 47.803 | 47.443 | 46.324 | 45.964 | 44.845
53.746 |  | G53.746x2.309 | G 1 3/4 | 11 | A | 53.746 | 53.386 | 52.267 | 52.087 | 50.788 |  |  | 50.788 | 51.428 | 52.267 | 52.447 | 53.746 |  | 44.4500 | 107.492 | 10.0000
53.746 |  | G53.746x2.309 | G 1 3/4 | 11 | B | 53.746 | 53.386 | 52.267 | 51.907 | 50.788
59.614 |  | G59.614x2.309 | G 2 | 11 | A | 59.614 | 59.254 | 58.135 | 57.955 | 56.656 |  |  | 56.656 | 57.296 | 58.135 | 58.315 | 59.614 |  | 50.8000 | 119.228 | 10.0000
59.614 |  | G59.614x2.309 | G 2 | 11 | B | 59.614 | 59.254 | 58.135 | 57.775 | 56.656
65.710 |  | G65.71x2.309 | G 2 1/4 | 11 | A | 65.710 | 65.276 | 64.231 | 64.014 | 62.752 |  |  | 62.752 | 63.392 | 64.231 | 64.448 | 65.710 |  | 57.1500 | 131.420 | 10.0000
65.710 |  | G65.71x2.309 | G 2 1/4 | 11 | B | 65.710 | 65.276 | 64.231 | 63.797 | 62.752
75.184 |  | G75.184x2.309 | G 2 1/2 | 11 | A | 75.184 | 74.750 | 73.705 | 73.488 | 72.226 |  |  | 72.226 | 72.866 | 73.705 | 73.922 | 75.184 |  |  | 150.368 | 10.0000
75.184 |  | G75.184x2.309 | G 2 1/2 | 11 | B | 75.184 | 74.750 | 73.705 | 73.271 | 72.226
81.534 |  | G81.534x2.309 | G 2 3/4 | 11 | A | 81.534 | 81.100 | 80.055 | 79.838 | 78.576 |  |  | 78.576 | 79.216 | 80.055 | 80.272 | 81.534 |  | 69.8500 | 163.068 | 10.0000
81.534 |  | G81.534x2.309 | G 2 3/4 | 11 | B | 81.534 | 81.100 | 80.055 | 79.621 | 78.576
87.884 |  | G87.884x2.309 | G 3 | 11 | A | 87.884 | 87.450 | 86.405 | 86.188 | 84.926 |  |  | 84.926 | 85.566 | 86.405 | 86.622 | 87.884 |  | 76.2000 | 175.768 | 10.0000
87.884 |  | G87.884x2.309 | G 3 | 11 | B | 87.884 | 87.450 | 86.405 | 85.971 | 84.926
100.330 |  | G100.33x2.309 | G 3 1/2 | 11 | A | 100.330 | 99.896 | 98.851 | 98.634 | 97.372 |  |  | 97.372 | 98.012 | 98.851 | 99.068 | 100.330 |  | 88.9000 | 200.660 | 10.0000
100.330 |  | G100.33x2.309 | G 3 1/2 | 11 | B | 100.330 | 99.896 | 98.851 | 98.417 | 97.372
113.030 |  | G113.03x2.309 | G 4 | 11 | A | 113.030 | 112.596 | 111.551 | 111.334 | 110.072 |  |  | 110.072 | 110.712 | 111.551 | 111.768 | 113.030 |  | 101.6000 | 226.060 | 10.0000
113.030 |  | G113.03x2.309 | G 4 | 11 | B | 113.030 | 112.596 | 111.551 | 111.117 | 110.072
125.730 |  | G125.73x2.309 | G 4 1/2 | 11 | A | 125.730 | 125.296 | 124.251 | 124.034 | 122.772 |  |  | 122.772 | 123.412 | 124.251 | 124.468 | 125.730 |  | 114.3000 | 251.460 | 10.0000
125.730 |  | G125.73x2.309 | G 4 1/2 | 11 | B | 125.730 | 125.296 | 124.251 | 123.817 | 122.772
138.430 |  | G138.43x2.309 | G 5 | 11 | A | 138.430 | 137.996 | 136.951 | 136.734 | 135.472 |  |  | 135.472 | 136.112 | 136.951 | 137.168 | 138.430 |  | 127.0000 | 276.860 | 10.0000
138.430 |  | G138.43x2.309 | G 5 | 11 | B | 138.430 | 137.996 | 136.951 | 136.517 | 135.472
151.130 |  | G151.13x2.309 | G 5 1/2 | 11 | A | 151.130 | 150.696 | 149.651 | 149.434 | 148.172 |  |  | 148.172 | 148.812 | 149.651 | 149.868 | 151.130 |  | 139.7000 | 302.260 | 10.0000
151.130 |  | G151.13x2.309 | G 5 1/2 | 11 | B | 151.130 | 150.696 | 149.651 | 149.217 | 148.172
163.830 |  | G163.83x2.309 | G 6 | 11 | A | 163.830 | 163.396 | 162.351 | 162.134 | 160.872 |  |  | 160.872 | 161.512 | 162.351 | 162.568 | 163.830 |  | 152.4000 | 327.660 | 10.0000
163.830 |  | G163.83x2.309 | G 6 | 11 | B | 163.830 | 163.396 | 162.351 | 161.917 | 160.872

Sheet: JIS Pipe Threads
M Q | JIS Pipe Threads |  | Sort Order -12 |  | External |  |  |  |  |  |  | Internal
 |  |  |  |  |  | Major Dia |  | Pitch Dia |  | Minor Dia |  |  | Minor Dia |  | Pitch Dia |  | Major Dia |  | Tap Drill | Thread Depth | Thread Runouts
Size | Size Suffix | Thread Designation | Custom Thread Designation | TPI | Class | Max | Min | Max | Min | Max | Min | Class | Min | Max | Min | Max | Min | Max | Basic |  | Basic
7.723 |  | G7.723x0.907 | G 1/16 | 28 | A | 7.723 | 7.509 | 7.142 | 7.035 | 6.561 |  |  | 6.561 | 6.834 | 7.142 | 7.249 | 7.723 |  | 1.5875 | 15.446 | 4.5000
7.723 |  | G7.723x0.907 | G 1/16 | 28 | B | 7.723 | 7.509 | 7.142 | 6.928 | 6.561
9.728 |  | G9.728x0.907 | G 1/8 | 28 | A | 9.728 | 9.514 | 9.147 | 9.040 | 8.566 |  |  | 8.566 | 8.848 | 9.147 | 9.254 | 9.728 |  | 3.1750 | 19.456 | 4.5000
9.728 |  | G9.728x0.907 | G 1/8 | 28 | B | 9.728 | 9.514 | 9.147 | 8.933 | 8.566
13.157 |  | G13.157x1.337 | G 1/4 | 19 | A | 13.157 | 12.907 | 12.301 | 12.176 | 11.445 |  |  | 11.445 | 11.89 | 12.301 | 12.426 | 13.157 |  | 6.3500 | 26.314 | 6.5000
13.157 |  | G13.157x1.337 | G 1/4 | 19 | B | 13.157 | 12.907 | 12.301 | 12.051 | 11.445
16.662 |  | G16.662x1.337 | G 3/8 | 19 | A | 16.662 | 16.412 | 15.806 | 15.681 | 14.950 |  |  | 14.95 | 15.395 | 15.806 | 15.931 | 16.662 |  | 9.5250 | 33.324 | 6.5000
16.662 |  | G16.662x1.337 | G 3/8 | 19 | B | 16.662 | 16.412 | 15.806 | 15.556 | 14.950
20.955 |  | G20.955x1.814 | G 1/2 | 14 | A | 20.955 | 20.671 | 19.793 | 19.651 | 18.631 |  |  | 18.631 | 19.172 | 19.793 | 19.935 | 20.955 |  | 12.7000 | 41.910 | 8.5000
20.955 |  | G20.955x1.814 | G 1/2 | 14 | B | 20.955 | 20.671 | 19.793 | 19.509 | 18.631
22.911 |  | G22.911x1.814 | G 5/8 | 14 | A | 22.911 | 22.627 | 21.749 | 21.607 | 20.587 |  |  | 20.587 | 21.128 | 21.749 | 21.891 | 22.911 |  |  | 45.822 | 8.5000
22.911 |  | G22.911x1.814 | G 5/8 | 14 | B | 22.911 | 22.627 | 21.749 | 21.465 | 20.587
26.441 |  | G26.441x1.814 | G 3/4 | 14 | A | 26.441 | 26.157 | 25.279 | 25.137 | 24.117 |  |  | 24.117 | 24.658 | 25.279 | 25.421 | 26.441 |  | 15.8750 | 52.882 | 8.5000
26.441 |  | G26.441x1.814 | G 3/4 | 14 | B | 26.441 | 26.157 | 25.279 | 24.995 | 24.117
30.201 |  | G30.201x1.814 | G 7/8 | 14 | A | 30.201 | 29.917 | 29.039 | 28.897 | 27.877 |  |  | 27.877 | 28.418 | 29.039 | 29.181 | 30.201 |  | 22.2250 | 60.402 | 8.8000
30.201 |  | G30.201x1.814 | G 7/8 | 14 | B | 30.201 | 29.917 | 29.039 | 28.755 | 27.877
33.249 |  | G33.249x2.309 | G 1 | 11 | A | 33.249 | 32.889 | 31.770 | 31.590 | 30.291 |  |  | 30.291 | 30.931 | 31.77 | 31.95 | 33.249 |  | 25.4000 | 66.498 | 10.0000
33.249 |  | G33.249x2.309 | G 1 | 11 | B | 33.249 | 32.889 | 31.770 | 31.410 | 30.291
37.897 |  | G37.897x2.309 | G 1 1/8 | 11 | A | 37.897 | 37.537 | 36.418 | 36.238 | 34.939 |  |  | 34.939 | 35.579 | 36.418 | 36.598 | 37.897 |  | 28.5750 | 75.794 | 10.0000
37.897 |  | G37.897x2.309 | G 1 1/8 | 11 | B | 37.897 | 37.537 | 36.418 | 36.058 | 34.939
41.910 |  | G41.91x2.309 | G 1 1/4 | 11 | A | 41.910 | 41.550 | 40.431 | 40.251 | 38.952 |  |  | 38.952 | 39.592 | 40.431 | 40.611 | 41.910 |  | 31.7500 | 83.820 | 10.0000
41.910 |  | G41.91x2.309 | G 1 1/4 | 11 | B | 41.910 | 41.550 | 40.431 | 40.071 | 38.952
47.803 |  | G47.803x2.309 | G 1 1/2 | 11 | A | 47.803 | 47.443 | 46.324 | 46.144 | 44.845 |  |  | 44.845 | 45.485 | 46.324 | 46.504 | 47.803 |  | 38.1000 | 95.606 | 10.0000
47.803 |  | G47.803x2.309 | G 1 1/2 | 11 | B | 47.803 | 47.443 | 46.324 | 45.964 | 44.845
53.746 |  | G53.746x2.309 | G 1 3/4 | 11 | A | 53.746 | 53.386 | 52.267 | 52.087 | 50.788 |  |  | 50.788 | 51.428 | 52.267 | 52.447 | 53.746 |  | 44.4500 | 107.492 | 10.0000
53.746 |  | G53.746x2.309 | G 1 3/4 | 11 | B | 53.746 | 53.386 | 52.267 | 51.907 | 50.788
59.614 |  | G59.614x2.309 | G 2 | 11 | A | 59.614 | 59.254 | 58.135 | 57.955 | 56.656 |  |  | 56.656 | 57.296 | 58.135 | 58.315 | 59.614 |  | 50.8000 | 119.228 | 10.0000
59.614 |  | G59.614x2.309 | G 2 | 11 | B | 59.614 | 59.254 | 58.135 | 57.775 | 56.656
65.710 |  | G65.71x2.309 | G 2 1/4 | 11 | A | 65.710 | 65.276 | 64.231 | 64.014 | 62.752 |  |  | 62.752 | 63.392 | 64.231 | 64.448 | 65.710 |  | 57.1500 | 131.420 | 10.0000
65.710 |  | G65.71x2.309 | G 2 1/4 | 11 | B | 65.710 | 65.276 | 64.231 | 63.797 | 62.752
75.184 |  | G75.184x2.309 | G 2 1/2 | 11 | A | 75.184 | 74.750 | 73.705 | 73.488 | 72.226 |  |  | 72.226 | 72.866 | 73.705 | 73.922 | 75.184 |  |  | 150.368 | 10.0000
75.184 |  | G75.184x2.309 | G 2 1/2 | 11 | B | 75.184 | 74.750 | 73.705 | 73.271 | 72.226
81.534 |  | G81.534x2.309 | G 2 3/4 | 11 | A | 81.534 | 81.100 | 80.055 | 79.838 | 78.576 |  |  | 78.576 | 79.216 | 80.055 | 80.272 | 81.534 |  | 69.8500 | 163.068 | 10.0000
81.534 |  | G81.534x2.309 | G 2 3/4 | 11 | B | 81.534 | 81.100 | 80.055 | 79.621 | 78.576
87.884 |  | G87.884x2.309 | G 3 | 11 | A | 87.884 | 87.450 | 86.405 | 86.188 | 84.926 |  |  | 84.926 | 85.566 | 86.405 | 86.622 | 87.884 |  | 76.2000 | 175.768 | 10.0000
87.884 |  | G87.884x2.309 | G 3 | 11 | B | 87.884 | 87.450 | 86.405 | 85.971 | 84.926
100.330 |  | G100.33x2.309 | G 3 1/2 | 11 | A | 100.330 | 99.896 | 98.851 | 98.634 | 97.372 |  |  | 97.372 | 98.012 | 98.851 | 99.068 | 100.330 |  | 88.9000 | 200.660 | 10.0000
100.330 |  | G100.33x2.309 | G 3 1/2 | 11 | B | 100.330 | 99.896 | 98.851 | 98.417 | 97.372
113.030 |  | G113.03x2.309 | G 4 | 11 | A | 113.030 | 112.596 | 111.551 | 111.334 | 110.072 |  |  | 110.072 | 110.712 | 111.551 | 111.768 | 113.030 |  | 101.6000 | 226.060 | 10.0000
113.030 |  | G113.03x2.309 | G 4 | 11 | B | 113.030 | 112.596 | 111.551 | 111.117 | 110.072
125.730 |  | G125.73x2.309 | G 4 1/2 | 11 | A | 125.730 | 125.296 | 124.251 | 124.034 | 122.772 |  |  | 122.772 | 123.412 | 124.251 | 124.468 | 125.730 |  | 114.3000 | 251.460 | 10.0000
125.730 |  | G125.73x2.309 | G 4 1/2 | 11 | B | 125.730 | 125.296 | 124.251 | 123.817 | 122.772
138.430 |  | G138.43x2.309 | G 5 | 11 | A | 138.430 | 137.996 | 136.951 | 136.734 | 135.472 |  |  | 135.472 | 136.112 | 136.951 | 137.168 | 138.430 |  | 127.0000 | 276.860 | 10.0000
138.430 |  | G138.43x2.309 | G 5 | 11 | B | 138.430 | 137.996 | 136.951 | 136.517 | 135.472
151.130 |  | G151.13x2.309 | G 5 1/2 | 11 | A | 151.130 | 150.696 | 149.651 | 149.434 | 148.172 |  |  | 148.172 | 148.812 | 149.651 | 149.868 | 151.130 |  | 139.7000 | 302.260 | 10.0000
151.130 |  | G151.13x2.309 | G 5 1/2 | 11 | B | 151.130 | 150.696 | 149.651 | 149.217 | 148.172
163.830 |  | G163.83x2.309 | G 6 | 11 | A | 163.830 | 163.396 | 162.351 | 162.134 | 160.872 |  |  | 160.872 | 161.512 | 162.351 | 162.568 | 163.830 |  | 152.4000 | 327.660 | 10.0000
163.830 |  | G163.83x2.309 | G 6 | 11 | B | 163.830 | 163.396 | 162.351 | 161.917 | 160.872

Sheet: DIN Pipe Threads
M Q | DIN Pipe Threads |  | Sort Order - 18 |  | External |  |  |  |  |  |  | Internal
 |  |  |  |  |  | Major Dia |  | Pitch Dia |  | Minor Dia |  |  | Minor Dia |  | Pitch Dia |  | Major Dia |  | Tap Drill | Thread Depth | Thread Runouts
Size | Size Suffix | Thread Designation | Custom Thread Designation | TPI | Class | Max | Min | Max | Min | Max | Min | Class | Min | Max | Min | Max | Min | Max | Basic
7.723 |  | G7.723x0.907 | G 1/16 | 28 | A | 7.723 | 7.509 | 7.142 | 7.035 | 6.561 |  |  | 6.561 | 6.834 | 7.142 | 7.249 | 7.723 |  | 1.5875 | 15.446 | 4.5000
7.723 |  | G7.723x0.907 | G 1/16 | 28 | B | 7.723 | 7.509 | 7.142 | 6.928 | 6.561
9.728 |  | G9.728x0.907 | G 1/8 | 28 | A | 9.728 | 9.514 | 9.147 | 9.040 | 8.566 |  |  | 8.566 | 8.848 | 9.147 | 9.254 | 9.728 |  | 3.1750 | 19.456 | 4.5000
9.728 |  | G9.728x0.907 | G 1/8 | 28 | B | 9.728 | 9.514 | 9.147 | 8.933 | 8.566
13.157 |  | G13.157x1.337 | G 1/4 | 19 | A | 13.157 | 12.907 | 12.301 | 12.176 | 11.445 |  |  | 11.445 | 11.89 | 12.301 | 12.426 | 13.157 |  | 6.3500 | 26.314 | 6.5000
13.157 |  | G13.157x1.337 | G 1/4 | 19 | B | 13.157 | 12.907 | 12.301 | 12.051 | 11.445
16.662 |  | G16.662x1.337 | G 3/8 | 19 | A | 16.662 | 16.412 | 15.806 | 15.681 | 14.950 |  |  | 14.95 | 15.395 | 15.806 | 15.931 | 16.662 |  | 9.5250 | 33.324 | 6.5000
16.662 |  | G16.662x1.337 | G 3/8 | 19 | B | 16.662 | 16.412 | 15.806 | 15.556 | 14.950
20.955 |  | G20.955x1.814 | G 1/2 | 14 | A | 20.955 | 20.671 | 19.793 | 19.651 | 18.631 |  |  | 18.631 | 19.172 | 19.793 | 19.935 | 20.955 |  | 12.7000 | 41.910 | 8.5000
20.955 |  | G20.955x1.814 | G 1/2 | 14 | B | 20.955 | 20.671 | 19.793 | 19.509 | 18.631
22.911 |  | G22.911x1.814 | G 5/8 | 14 | A | 22.911 | 22.627 | 21.749 | 21.607 | 20.587 |  |  | 20.587 | 21.128 | 21.749 | 21.891 | 22.911 |  |  | 45.822 | 8.5000
22.911 |  | G22.911x1.814 | G 5/8 | 14 | B | 22.911 | 22.627 | 21.749 | 21.465 | 20.587
26.441 |  | G26.441x1.814 | G 3/4 | 14 | A | 26.441 | 26.157 | 25.279 | 25.137 | 24.117 |  |  | 24.117 | 24.658 | 25.279 | 25.421 | 26.441 |  | 15.8750 | 52.882 | 8.5000
26.441 |  | G26.441x1.814 | G 3/4 | 14 | B | 26.441 | 26.157 | 25.279 | 24.995 | 24.117
30.201 |  | G30.201x1.814 | G 7/8 | 14 | A | 30.201 | 29.917 | 29.039 | 28.897 | 27.877 |  |  | 27.877 | 28.418 | 29.039 | 29.181 | 30.201 |  | 22.2250 | 60.402 | 8.5000
30.201 |  | G30.201x1.814 | G 7/8 | 14 | B | 30.201 | 29.917 | 29.039 | 28.755 | 27.877
33.249 |  | G33.249x2.309 | G 1 | 11 | A | 33.249 | 32.889 | 31.770 | 31.590 | 30.291 |  |  | 30.291 | 30.931 | 31.77 | 31.95 | 33.249 |  | 25.4000 | 66.498 | 10.5000
33.249 |  | G33.249x2.309 | G 1 | 11 | B | 33.249 | 32.889 | 31.770 | 31.410 | 30.291
37.897 |  | G37.897x2.309 | G 1 1/8 | 11 | A | 37.897 | 37.537 | 36.418 | 36.238 | 34.939 |  |  | 34.939 | 35.579 | 36.418 | 36.598 | 37.897 |  | 28.5750 | 75.794 | 10.5000
37.897 |  | G37.897x2.309 | G 1 1/8 | 11 | B | 37.897 | 37.537 | 36.418 | 36.058 | 34.939
41.910 |  | G41.91x2.309 | G 1 1/4 | 11 | A | 41.910 | 41.550 | 40.431 | 40.251 | 38.952 |  |  | 38.952 | 39.592 | 40.431 | 40.611 | 41.910 |  | 31.7500 | 83.820 | 10.5000
41.910 |  | G41.91x2.309 | G 1 1/4 | 11 | B | 41.910 | 41.550 | 40.431 | 40.071 | 38.952
47.803 |  | G47.803x2.309 | G 1 1/2 | 11 | A | 47.803 | 47.443 | 46.324 | 46.144 | 44.845 |  |  | 44.845 | 45.485 | 46.324 | 46.504 | 47.803 |  | 38.1000 | 95.606 | 10.5000
47.803 |  | G47.803x2.309 | G 1 1/2 | 11 | B | 47.803 | 47.443 | 46.324 | 45.964 | 44.845
53.746 |  | G53.746x2.309 | G 1 3/4 | 11 | A | 53.746 | 53.386 | 52.267 | 52.087 | 50.788 |  |  | 50.788 | 51.428 | 52.267 | 52.447 | 53.746 |  | 44.4500 | 107.492 | 10.5000
53.746 |  | G53.746x2.309 | G 1 3/4 | 11 | B | 53.746 | 53.386 | 52.267 | 51.907 | 50.788
59.614 |  | G59.614x2.309 | G 2 | 11 | A | 59.614 | 59.254 | 58.135 | 57.955 | 56.656 |  |  | 56.656 | 57.296 | 58.135 | 58.315 | 59.614 |  | 50.8000 | 119.228 | 10.5000
59.614 |  | G59.614x2.309 | G 2 | 11 | B | 59.614 | 59.254 | 58.135 | 57.775 | 56.656
65.710 |  | G65.71x2.309 | G 2 1/4 | 11 | A | 65.710 | 65.276 | 64.231 | 64.014 | 62.752 |  |  | 62.752 | 63.392 | 64.231 | 64.448 | 65.710 |  | 57.1500 | 131.420 | 10.5000
65.710 |  | G65.71x2.309 | G 2 1/4 | 11 | B | 65.710 | 65.276 | 64.231 | 63.797 | 62.752
75.184 |  | G75.184x2.309 | G 2 1/2 | 11 | A | 75.184 | 74.750 | 73.705 | 73.488 | 72.226 |  |  | 72.226 | 72.866 | 73.705 | 73.922 | 75.184 |  |  | 150.368 | 10.5000
75.184 |  | G75.184x2.309 | G 2 1/2 | 11 | B | 75.184 | 74.750 | 73.705 | 73.271 | 72.226
81.534 |  | G81.534x2.309 | G 2 3/4 | 11 | A | 81.534 | 81.100 | 80.055 | 79.838 | 78.576 |  |  | 78.576 | 79.216 | 80.055 | 80.272 | 81.534 |  | 69.8500 | 163.068 | 10.5000
81.534 |  | G81.534x2.309 | G 2 3/4 | 11 | B | 81.534 | 81.100 | 80.055 | 79.621 | 78.576
87.884 |  | G87.884x2.309 | G 3 | 11 | A | 87.884 | 87.450 | 86.405 | 86.188 | 84.926 |  |  | 84.926 | 85.566 | 86.405 | 86.622 | 87.884 |  | 76.2000 | 175.768 | 10.5000
87.884 |  | G87.884x2.309 | G 3 | 11 | B | 87.884 | 87.450 | 86.405 | 85.971 | 84.926
100.330 |  | G100.33x2.309 | G 3 1/2 | 11 | A | 100.330 | 99.896 | 98.851 | 98.634 | 97.372 |  |  | 97.372 | 98.012 | 98.851 | 99.068 | 100.330 |  | 88.9000 | 200.660 | 10.5000
100.330 |  | G100.33x2.309 | G 3 1/2 | 11 | B | 100.330 | 99.896 | 98.851 | 98.417 | 97.372
113.030 |  | G113.03x2.309 | G 4 | 11 | A | 113.030 | 112.596 | 111.551 | 111.334 | 110.072 |  |  | 110.072 | 110.712 | 111.551 | 111.768 | 113.030 |  | 101.6000 | 226.060 | 10.5000
113.030 |  | G113.03x2.309 | G 4 | 11 | B | 113.030 | 112.596 | 111.551 | 111.117 | 110.072
125.730 |  | G125.73x2.309 | G 4 1/2 | 11 | A | 125.730 | 125.296 | 124.251 | 124.034 | 122.772 |  |  | 122.772 | 123.412 | 124.251 | 124.468 | 125.730 |  | 114.3000 | 251.460 | 10.5000
125.730 |  | G125.73x2.309 | G 4 1/2 | 11 | B | 125.730 | 125.296 | 124.251 | 123.817 | 122.772
138.430 |  | G138.43x2.309 | G 5 | 11 | A | 138.430 | 137.996 | 136.951 | 136.734 | 135.472 |  |  | 135.472 | 136.112 | 136.951 | 137.168 | 138.430 |  | 127.0000 | 276.860 | 10.5000
138.430 |  | G138.43x2.309 | G 5 | 11 | B | 138.430 | 137.996 | 136.951 | 136.517 | 135.472
151.130 |  | G151.13x2.309 | G 5 1/2 | 11 | A | 151.130 | 150.696 | 149.651 | 149.434 | 148.172 |  |  | 148.172 | 148.812 | 149.651 | 149.868 | 151.130 |  | 139.7000 | 302.260 | 10.5000
151.130 |  | G151.13x2.309 | G 5 1/2 | 11 | B | 151.130 | 150.696 | 149.651 | 149.217 | 148.172
163.830 |  | G163.83x2.309 | G 6 | 11 | A | 163.830 | 163.396 | 162.351 | 162.134 | 160.872 |  |  | 160.872 | 161.512 | 162.351 | 162.568 | 163.830 |  | 152.4000 | 327.660 | 10.5000
163.830 |  | G163.83x2.309 | G 6 | 11 | B | 163.830 | 163.396 | 162.351 | 161.917 | 160.872

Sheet: BSP Pipe Threads
M Q | BSP Pipe Threads |  | Sort Order - 19 |  | External |  |  |  |  |  |  | Internal
 |  |  |  |  |  | Major Dia |  | Pitch Dia |  | Minor Dia |  |  | Minor Dia |  | Pitch Dia |  | Major Dia |  | Tap Drill | Thread Depth | Thread Runouts
Size | Size Suffix | Thread Designation | Custom Thread Designation | TPI | Class | Max | Min | Max | Min | Max | Min | Class | Min | Max | Min | Max | Min | Max | Basic |  | Basic
1/16 |  | G 1/16-28 | G 1/16-28 | 28 | A | 7.723 | 7.509 | 7.142 | 7.035 | 6.561 |  |  | 6.561 | 6.834 | 7.142 | 7.249 | 7.723 |  | 6.6000 | 15.4460 | 4.5000
1/16 |  | G 1/16-28 | G 1/16-28 | 28 | B | 7.723 | 7.509 | 7.142 | 7.035 | 6.561
1/8 |  | G 1/8-28 | G 1/8-28 | 28 | A | 9.728 | 9.514 | 9.147 | 9.040 | 8.566 |  |  | 8.566 | 8.848 | 9.147 | 9.254 | 9.728 |  | 8.7300 | 19.4560 | 4.5000
1/8 |  | G 1/8-28 | G 1/8-28 | 28 | B | 9.728 | 9.514 | 9.147 | 9.040 | 8.566
1/4 |  | G 1/4-19 | G 1/4-19 | 19 | A | 13.157 | 12.907 | 12.301 | 12.176 | 11.445 |  |  | 11.445 | 11.89 | 12.301 | 12.426 | 13.157 |  | 11.8000 | 26.3140 | 6.5000
1/4 |  | G 1/4-19 | G 1/4-19 | 19 | B | 13.157 | 12.907 | 12.301 | 12.176 | 11.445
3/8 |  | G 3/8-19 | G 3/8-19 | 19 | A | 16.662 | 16.412 | 15.806 | 15.681 | 14.950 |  |  | 14.95 | 15.395 | 15.806 | 15.931 | 16.662 |  | 15.2500 | 33.3240 | 6.5000
3/8 |  | G 3/8-19 | G 3/8-19 | 19 | B | 16.662 | 16.412 | 15.806 | 15.681 | 14.950
1/2 |  | G 1/2-14 | G 1/2-14 | 14 | A | 20.955 | 20.671 | 19.793 | 19.651 | 18.631 |  |  | 18.631 | 19.172 | 19.793 | 19.935 | 20.955 |  | 19.0500 | 41.9100 | 8.5000
1/2 |  | G 1/2-14 | G 1/2-14 | 14 | B | 20.955 | 20.671 | 19.793 | 19.651 | 18.631
5/8 |  | G 5/8-14 | G 5/8-14 | 14 | A | 22.911 | 22.627 | 21.749 | 21.607 | 20.587 |  |  | 20.587 | 21.128 | 21.749 | 21.891 | 22.911 |  | 21.0000 | 45.8220 | 8.5000
5/8 |  | G 5/8-14 | G 5/8-14 | 14 | B | 22.911 | 22.627 | 21.749 | 21.607 | 20.587
3/4 |  | G 3/4-14 | G 3/4-14 | 14 | A | 26.441 | 26.157 | 25.279 | 25.137 | 24.117 |  |  | 24.117 | 24.658 | 25.279 | 25.421 | 26.441 |  | 24.5000 | 52.8820 | 8.5000
3/4 |  | G 3/4-14 | G 3/4-14 | 14 | B | 26.441 | 26.157 | 25.279 | 25.137 | 24.117
7/8 |  | G 7/8-14 | G 7/8-14 | 14 | A | 30.201 | 29.917 | 29.039 | 28.897 | 27.877 |  |  | 27.877 | 28.418 | 29.039 | 29.181 | 30.201 |  | 28.2500 | 60.4020 | 8.5000
7/8 |  | G 7/8-14 | G 7/8-14 | 14 | B | 30.201 | 29.917 | 29.039 | 28.897 | 27.877
1 |  | G 1-11 | G 1-11 | 11 | A | 33.249 | 32.889 | 31.770 | 31.590 | 30.291 |  |  | 30.291 | 30.931 | 31.77 | 31.95 | 33.249 |  | 30.7500 | 66.4980 | 10.0000
1 |  | G 1-11 | G 1-11 | 11 | B | 33.249 | 32.889 | 31.770 | 31.590 | 30.291
1 1/4 |  | G 1 1/4-11 | G 1 1/4-11 | 11 | A | 41.910 | 41.550 | 40.431 | 40.251 | 38.952 |  |  | 38.952 | 39.592 | 40.431 | 40.611 | 41.910 |  | 39.5000 | 83.8200 | 10.0000
1 1/4 |  | G 1 1/4-11 | G 1 1/4-11 | 11 | B | 41.910 | 41.550 | 40.431 | 40.251 | 38.952
1 1/2 |  | G 1 1/2-11 | G 1 1/2-11 | 11 | A | 47.803 | 47.443 | 46.324 | 46.144 | 44.845 |  |  | 44.845 | 45.485 | 46.324 | 46.504 | 47.803 |  | 45.5000 | 95.6060 | 10.0000
1 1/2 |  | G 1 1/2-11 | G 1 1/2-11 | 11 | B | 47.803 | 47.443 | 46.324 | 46.144 | 44.845
1 3/4 |  | G 1 3/4-11 | G 1 3/4-11 | 11 | A | 53.746 | 53.386 | 52.267 | 52.087 | 50.788 |  |  | 50.788 | 51.428 | 52.267 | 52.447 | 53.746 |  | 51.0000 | 107.4920 | 10.0000
1 3/4 |  | G 1 3/4-11 | G 1 3/4-11 | 11 | B | 53.746 | 53.386 | 52.267 | 52.087 | 50.788
2 |  | G 2-11 | G 2-11 | 11 | A | 59.614 | 59.254 | 58.135 | 57.955 | 56.656 |  |  | 56.656 | 57.296 | 58.135 | 58.315 | 59.614 |  | 57.0000 | 119.2280 | 10.0000
2 |  | G 2-11 | G 2-11 | 11 | B | 59.614 | 59.254 | 58.135 | 57.955 | 56.656
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

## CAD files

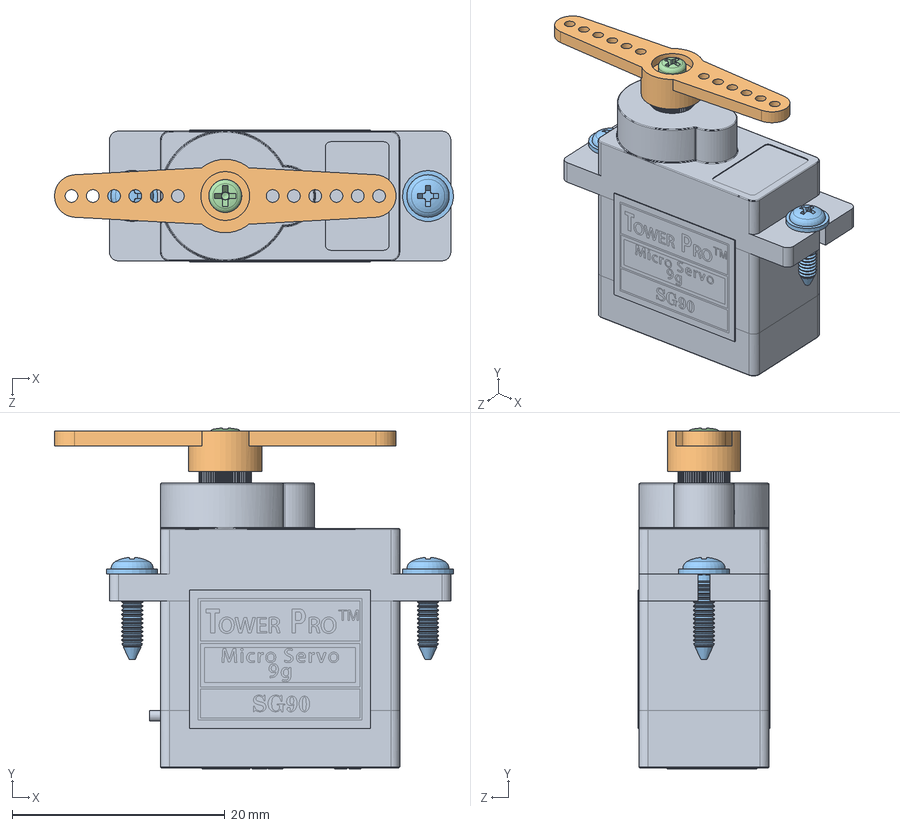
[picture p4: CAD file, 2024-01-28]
CAD-PSM/Ueberarbeiteter DaVincikopf/sg90-micro-servo-9g-tower-pro-1.snapshot.3/SG90 - Micro Servo 9g - Tower Pro.SLDASM
37.5 x 32.0 x 12.4 mm
SG90 - Micro Servo 9g - Tower Pro.1
SG90 - Micro Servo 9g - Tower Pro.3
SG90 - Micro Servo 9g - Tower Pro.5 x 2
SG90 - Micro Servo 9g - Tower Pro.6

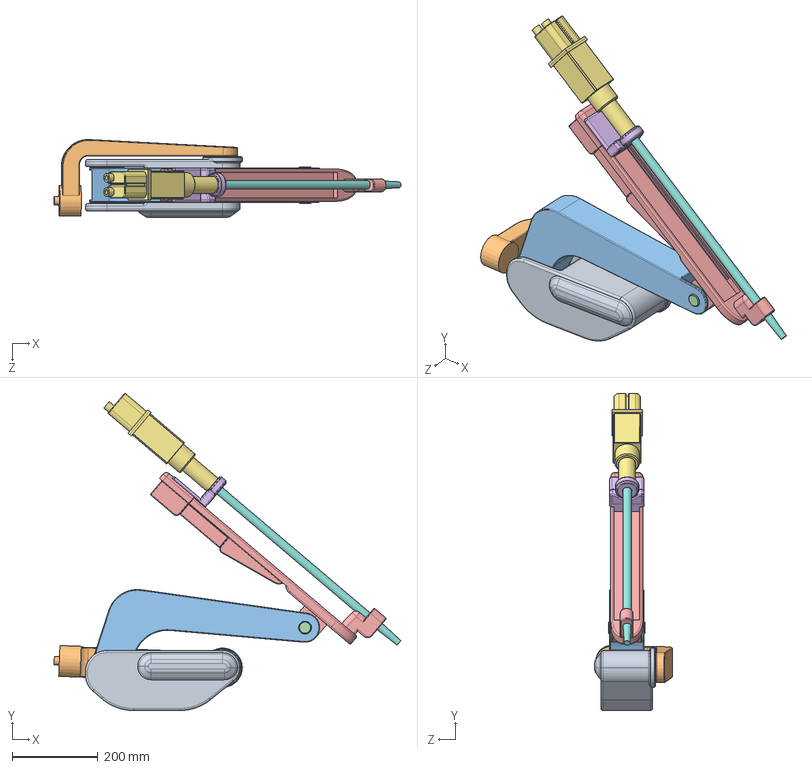
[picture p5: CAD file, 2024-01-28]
CAD-PSM/Ueberarbeiteter DaVincikopf/da-vinci-surgical-robot-1.snapshot.1/DaVinci/Assembly 3.SLDASM
808.7 x 739.3 x 181.2 mm

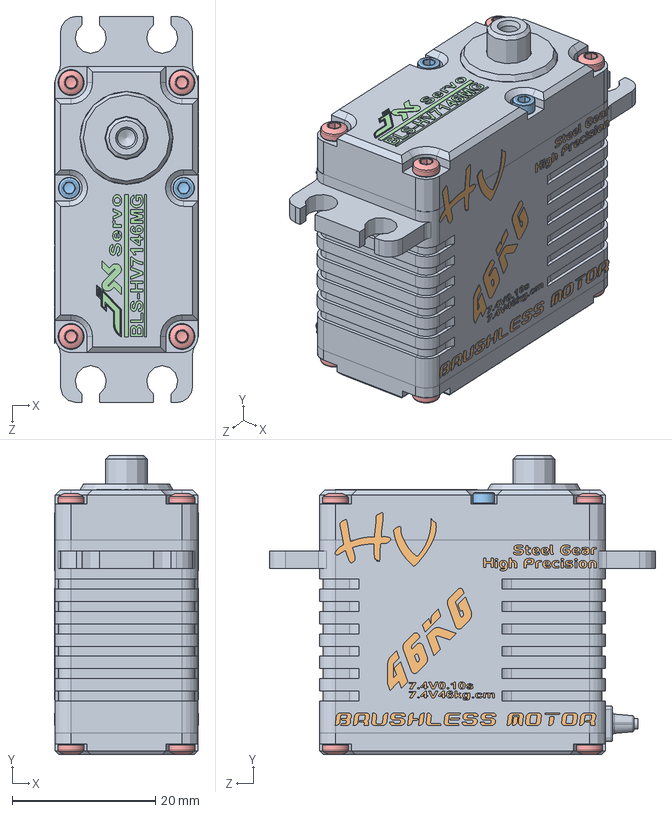
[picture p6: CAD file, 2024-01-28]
CAD-PSM/Ueberarbeiteter DaVincikopf/jx-bls-hv7146mg-rc-servo-1.snapshot.2/SolidWorks files/JX BLS-HV7146MG.SLDASM
20.2 x 41.8 x 54.0 mm
JX BLS-HV7146MG
46kg x 2
S1111612 JX x 2
Text on top
S1121612 JX x 8

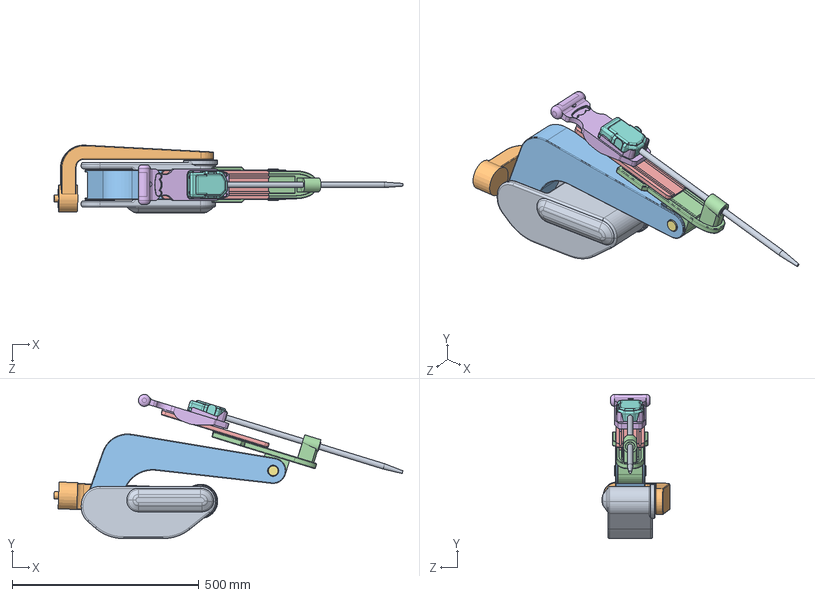
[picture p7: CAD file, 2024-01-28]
CAD-PSM/Ueberarbeiteter DaVincikopf/da-vinci-surgical-robot-1.snapshot.1/DaVinci/Assembly 2.SLDASM
935.5 x 386.6 x 181.2 mm

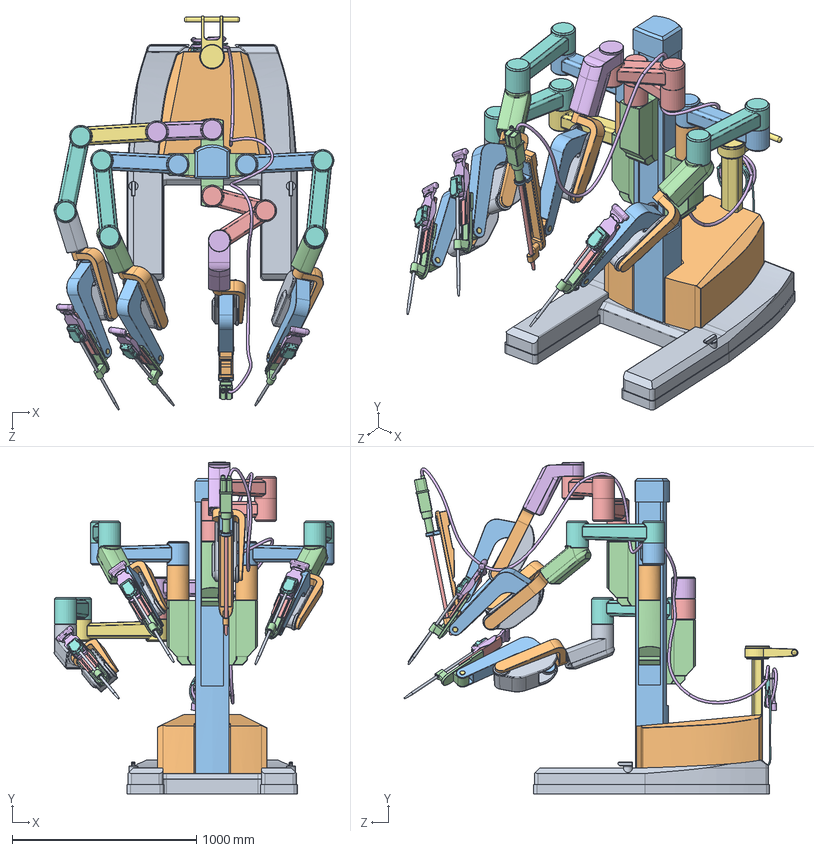
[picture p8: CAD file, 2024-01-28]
CAD-PSM/Ueberarbeiteter DaVincikopf/da-vinci-surgical-robot-1.snapshot.1/DaVinci/Assembly.SLDASM
1517.4 x 1798.8 x 2137.5 mm

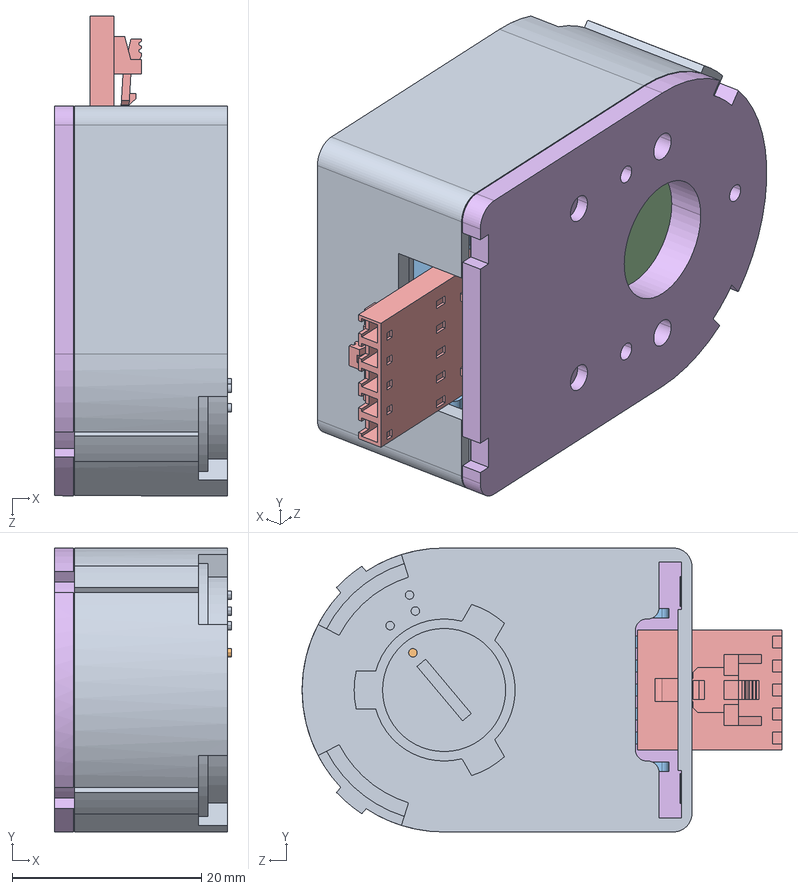
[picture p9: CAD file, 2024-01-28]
CAD-PSM/Downloads/AVAGO-HEDS-5540-A1.STEP
18.7 x 30.0 x 50.7 mm
BOX-HEDS-5540
HEDS-9040
HEDM-512
BASE-HEDS-5540

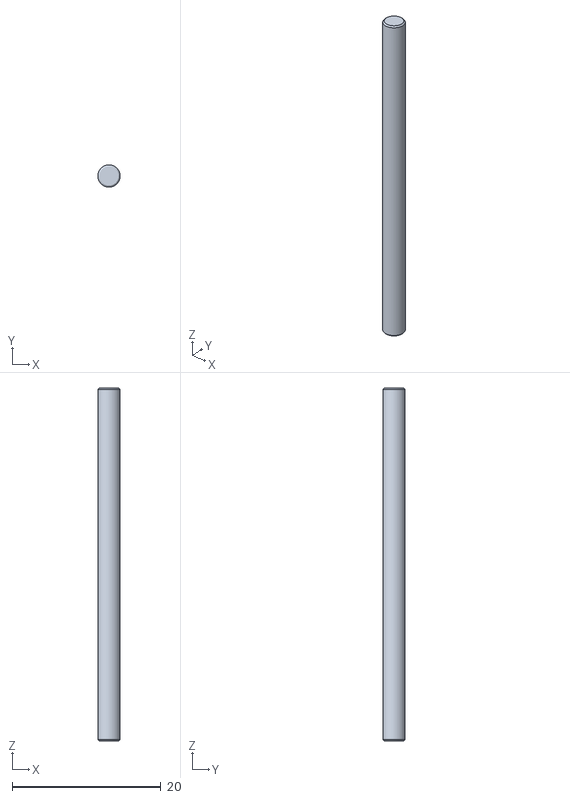
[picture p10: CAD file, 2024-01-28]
CAD-PSM/Riemenscheibe_Welle_Tension.stl
3.00 x 3.00 x 47.5

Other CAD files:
CAD-PSM/Drawings/Flansch_FemalePart_MainAxis_HeadConnectorBase_V2.1_Item40x40.dwg
CAD-PSM/Drawings/Flansch_Wellennabeverbindung_MainAxis.dwg
CAD-MTM/Templates/de-DE/Englisch/ANSI (Zoll).dwg
CAD-MTM/Templates/de-DE/Metrisch/BSI.dwg
CAD-MTM/Templates/de-DE/Norm.dwg
CAD-MTM/Templates/Englisch/ANSI (Zoll).dwg
CAD-MTM/Templates/Metrisch/am_din.dwg
CAD-MTM/Templates/Norm.dwg
CAD-PSM/Drawings/Welle_Flachstelle.dwg
CAD-PSM/Templates/English/ANSI (in).dwg
CAD-PSM/Templates/Metric/BSI.dwg
CAD-MTM/Arm_left_v3.iam
CAD-MTM/Arm_right_v3.iam
CAD-MTM/BNO055.ipt
CAD-MTM/Ball_Joint_Ball.ipt
CAD-MTM/CounterWeightFixation_left.ipt
CAD-MTM/CounterWeightFixation_oldVersion.ipt
CAD-MTM/CounterWeights_Brass.ipt
CAD-MTM/DIN 720 SKF - SKF 32004 X_Q.ipt
CAD-MTM/DIN 720 SKF - SKF 32005 X_Q.ipt
CAD-MTM/DIN 981 - KM 3.ipt
CAD-MTM/DIN 988 - 6 x 12 x 0,5.ipt
CAD-MTM/DIN EN ISO 4017 - M6 x 12.ipt
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

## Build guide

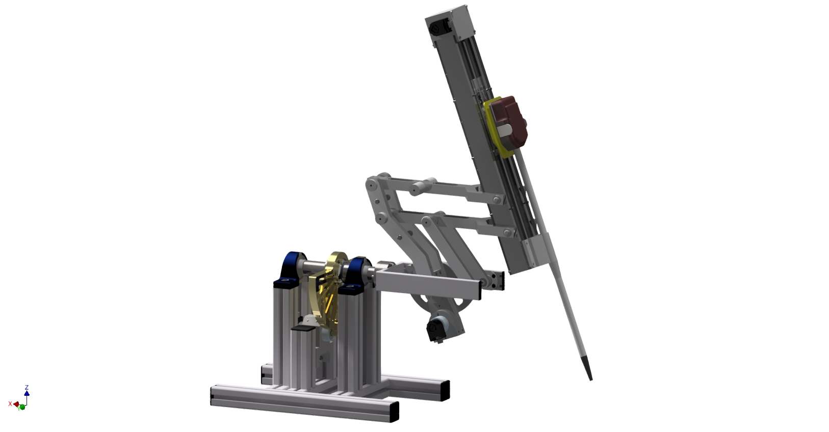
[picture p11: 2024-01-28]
CAD-PSM/RenderedImages/Assembly_v2_Rillenkugellager.jpg

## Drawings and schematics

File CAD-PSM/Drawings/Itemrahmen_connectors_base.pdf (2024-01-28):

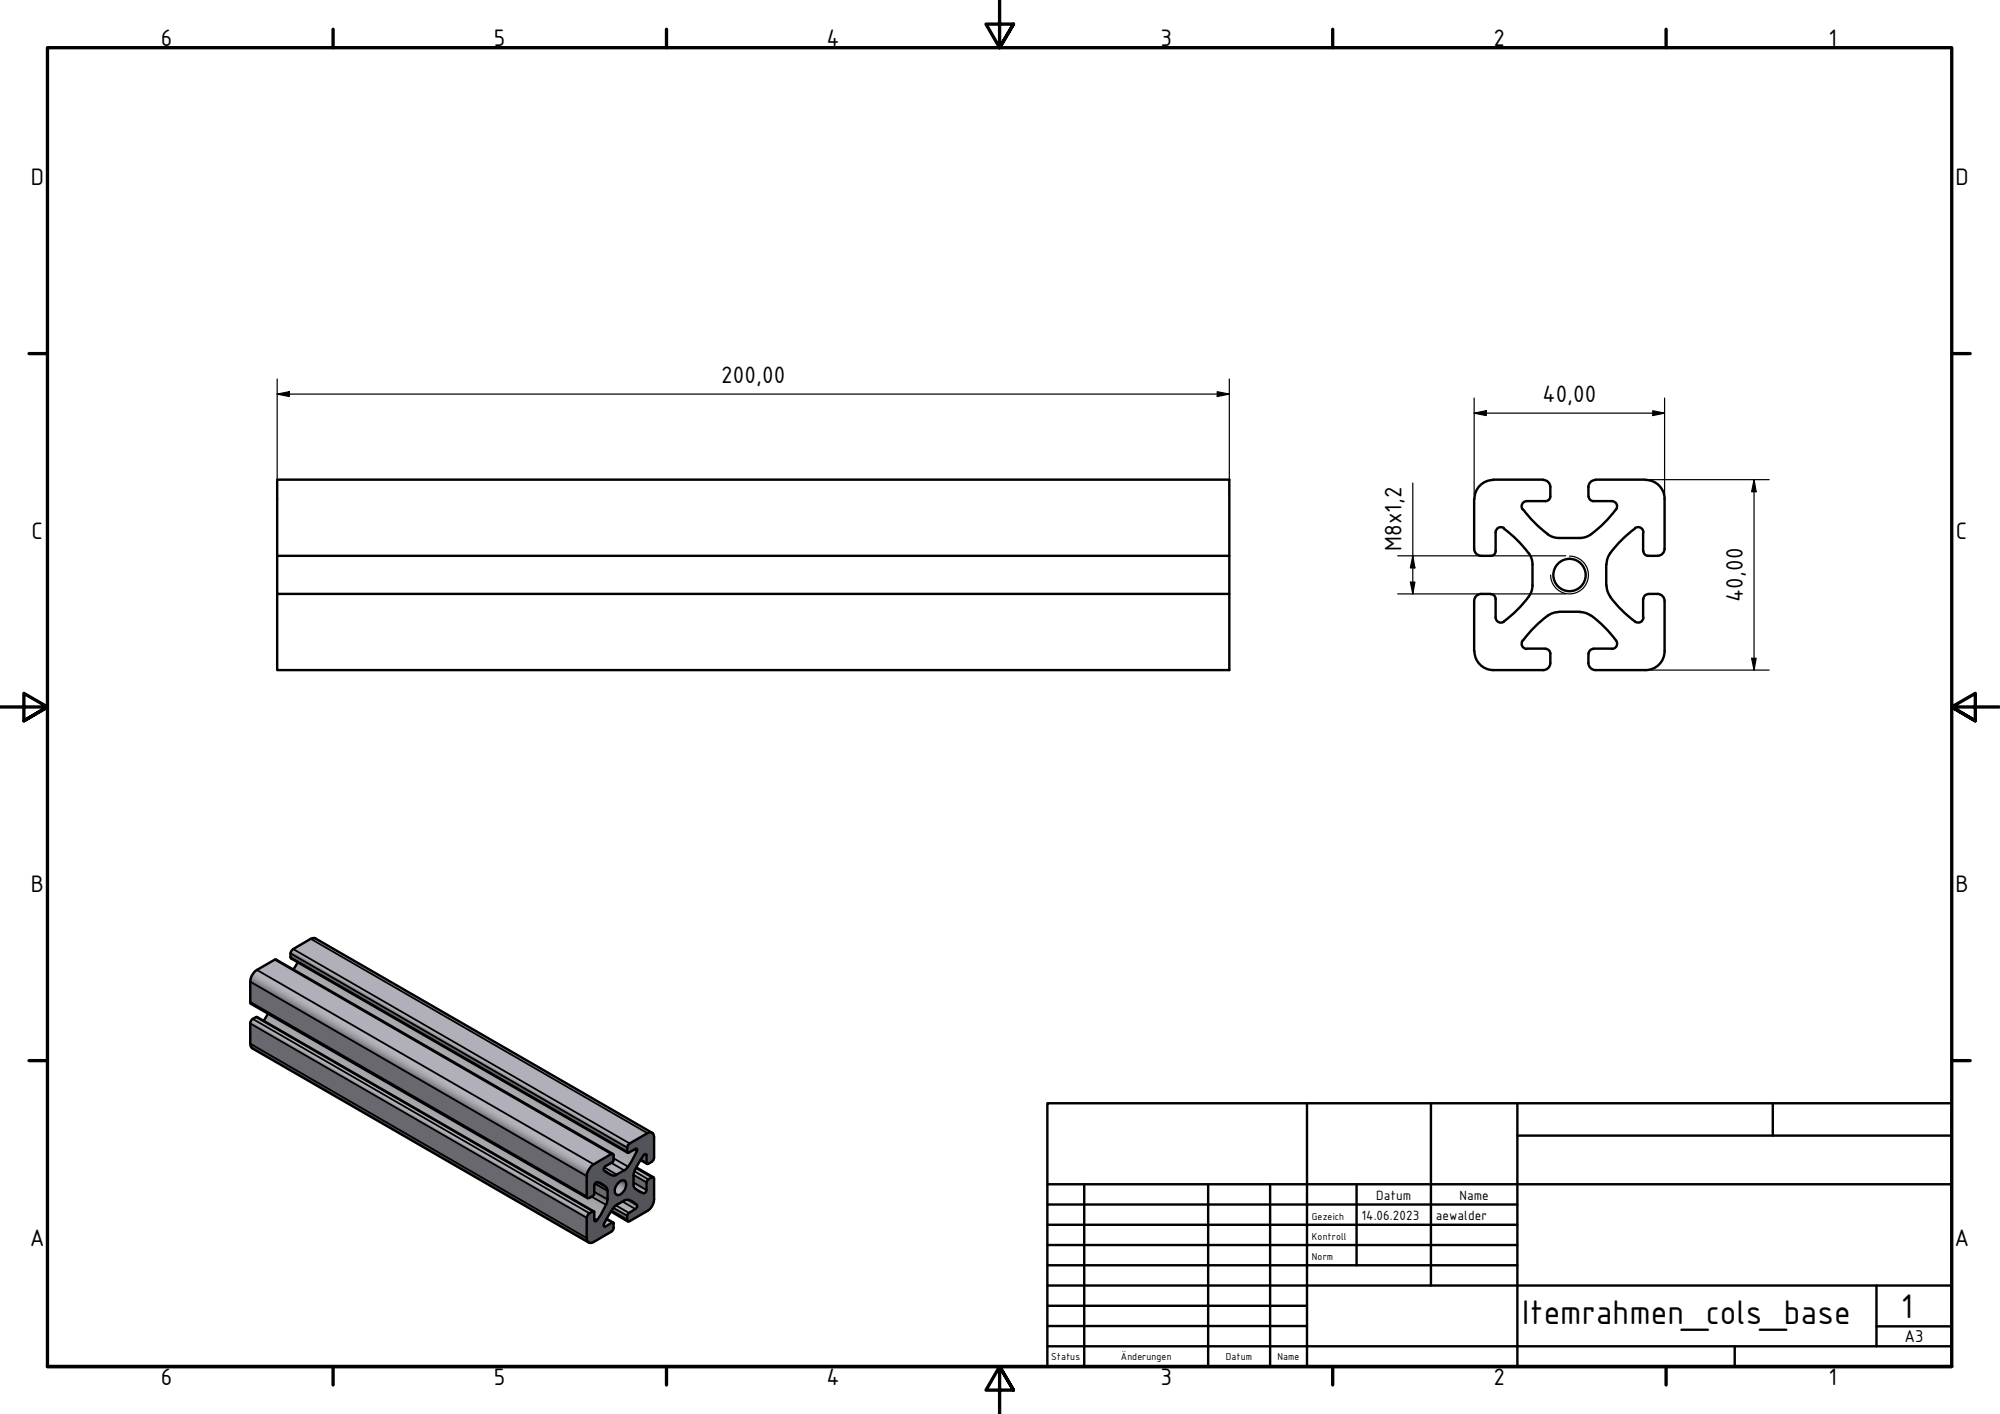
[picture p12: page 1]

Datum | Name

Gezeich | 14.06.2023 | aewalder

Kontroll

Norm

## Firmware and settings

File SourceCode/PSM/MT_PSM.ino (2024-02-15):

//=======================================================
//======                 Makros                   =======
//=======================================================
//Correct clock
//#define CORRECT_CLOCK 8     //Required for Arduino Mega
//#define micros() (micros() / CORRECT_CLOCK)
//#define millis() (millis() / CORRECT_CLOCK)

//Define Pins
#define ENC1_A 0
#define ENC1_B 1
#define ENC2_A 2
#define ENC2_B 3
#define ENC3_A 4
#define ENC3_B 5

#define DC1_PWM 6
#define DC2_PWM 7
#define DC3_PWM 8

#define DC1_DIR 24
#define DC2_DIR 25
#define DC3_DIR 26

#define SERVO1 9
#define SERVO2 10
#define SERVO3 11
#define SERVO4 12

#define LS1_NC 22
#define LS1_NO 23
#define LS2_NC 20
#define LS2_NO 21
#define LS3_NC 18
#define LS3_NO 19


// Math constants
#define PI 3.1415926535897932384626433832795

#define PSM_L
//#define PSM_R

//=======================================================
//======            Include libraries             =======
//=======================================================

//#include <avr/wdt.h>  //Watchdog Timer Library
//#include <Arduino.h>
#include "I2Cdev.h"
#include <stdfix.h>
#include <math.h>
#include "CytronMotorDriver.h"
#include <Servo.h>
#include <SPI.h>
#include <SD.h>
#include <util/atomic.h>
#include <Encoder.h>
#define ENCODER_OPTIMIZE_INTERRUPTS
#include <SPI.h>
#include <SD.h>
#include <SoftwareSerial.h>

#if I2CDEV_IMPLEMENTATION == I2CDEV_ARDUINO_WIRE
#include "Wire.h"
#endif

//=======================================================
//======             GLOBAL VARIABLES             =======
//=======================================================

//----------Timer variables for recording
unsigned long stepResponsetimer;
unsigned long rec_start_time;
unsigned long rec_time = 5000;
bool rec_flag = false;
bool startRec = false;

//----------Define SD card object
File dataFile;

//----------State of Development
String refDevState = "auto";  //Uncomment if auto reference works
//String refDevState = "manual";

//----------Configure the motor driver.
CytronMD motor1(PWM_DIR, DC1_PWM, DC1_DIR);  // PWM 1 = Pin 4, DIR 1 = Pin 7.
CytronMD motor2(PWM_DIR, DC2_PWM, DC2_DIR);  // PWM 2 = Pin 5, DIR 2 = Pin 8.
CytronMD motor3(PWM_DIR, DC3_PWM, DC3_DIR);  // PWM 2 = Pin 6, DIR 2 = Pin 9.
CytronMD motor[3] = { motor1, motor2, motor3 };

//----------Encoder objects
Encoder Enc1(ENC1_B, ENC1_A);
Encoder Enc2(ENC2_B, ENC2_A);
Encoder Enc3(ENC3_B, ENC3_A);

//----------Configure Servo objects
Servo servo1;
Servo servo2;
Servo servo3;
Servo servo4;
Servo servos[4] = { servo1, servo2, servo3, servo4 };

//----------Servo variables
#ifdef PSM_R
int servo_val1, servo_val2, servo_val3, servo_val4;
int servo_val[4] = { servo_val1, servo_val2, servo_val3, servo_val4 };
int servo_off1 = 115, servo_off2 = 92, servo_off3 = 80, servo_off4 = 105;
int servo_off[4] = { servo_off1, servo_off2, servo_off3, servo_off4 };
#endif

#ifdef PSM_L
int servo_val1, servo_val2, servo_val3, servo_val4;
int servo_val[4] = { servo_val1, servo_val2, servo_val3, servo_val4 };
int servo_off1 = 100, servo_off2 = 97, servo_off3 = 90, servo_off4 = 92;
int servo_off[4] = { servo_off1, servo_off2, servo_off3, servo_off4 };
#endif

//----------Optical encoder variables
long raw_pos1, raw_pos2, raw_pos3;
long pos[3] = { raw_pos1, raw_pos2, raw_pos3 };
const float res_avago = 0.18;
//----------Sampling Time variables
float prevT = 0;
float currT;
float dt;

//----------State machine variables
int state;
int home = 0;
int retrieve = 1;
int reference = 2;
int move_zero = 3;
int dmg_cnt;

bool ref1, ref2, ref3;
bool ref[3] = { ref1, ref2, ref3 };
bool ref_drive1, ref_drive2, ref_drive3;
bool refpos1, refpos2, refpos3;

int p_counter1 = 0, p_counter2 = 0, p_counter3 = 0;
long ref_counter1 = 0, ref_counter2 = 0, ref_counter3 = 0;
const int threshold = 10;

float pos1, pos2, pos3;  //In angular position of axis
float ref_offset1 = -25, ref_offset2 = -35, ref_offset3 = 0;

//----------Transmission ration
const float trans1 = 20.00;
const float trans2 = 13.33;

//-----Enc variables
float min_res1 = 0.01, min_res2 = 0.02, min_res3 = 0.03;
float min_res[3] = { min_res1, min_res2, min_res3 };

//----------Joint values
double q1, q2, q3, q4, q5, q6, q7;
double q[3] = { q1, q2, q3 };
//----------Corrdinates
double x, y, z;
float x_m, y_m, z_m;

//----------Geometric Variables
double L_RCM = 455.99;
double L_tool = 432.5;
double d0 = -L_RCM + L_tool;

//----------Maxon Motor variables
int speed1, speed2, speed3;
int m_speed[3] = { speed1, speed2, speed3 };
int dir1, dir2, dir3;
int dir[3] = { dir1, dir2, dir3 };

//----------PID controller variables
float kp, ki, kd;
String c_mode;

float integral1, integral2, integral3;
float integral[3] = { integral1, integral2, integral3 };

float prev_e1 = 0, prev_e2 = 0, prev_e3 = 0;  //Last Error
float prev_e[3] = { prev_e1, prev_e2, prev_e3 };
float rate_e1, rate_e2, rate_e3;  //Current derivative
float rate_e[3] = { rate_e1, rate_e2, rate_e3 };
float prev_rate_e1 = 0, prev_rate_e2 = 0, prev_rate_e3 = 0;  //Last derivative
float prev_rate_e[3] = { prev_rate_e1, prev_rate_e2, prev_rate_e3 };

float target_pos1, target_pos2, target_pos3, target_pos4, target_pos5, target_pos6, target_pos7;
float* target_pos[7] = { &target_pos1, &target_pos2, &target_pos3, &target_pos4, &target_pos5, &target_pos6, &target_pos7 };
float control_val1, control_val2, control_val3;
float control_values[3] = { control_val1, control_val2, control_val3 };
float sat_control_val1, sat_control_val2, sat_control_val3;
float sat_control_values[3] = { sat_control_val1, sat_control_val2, sat_control_val3 };

bool clamp_I1 = false, clamp_I2 = false, clamp_I3 = false;
bool clamp_I[3] = { clamp_I1, clamp_I2, clamp_I3 };


//----------Receive Data
const byte numChars = 81;  //32
char receivedChars[numChars];
char tempChars[numChars];  // temporary array for use when parsing
//variables to temp hold the parsed data
char messageFromPC[numChars] = { 0 };
int integerFromPC = 0;
float floatFromPC = 0.0;
boolean newData = false;

//----------Lp filter variables
float dt_xn1;
float dt_yn1;
bool first = true;

float pre_rate_filter_e1 = 0, pre_rate_filter_e2 = 0, pre_rate_filter_e3 = 0;
float pre_rate_filter[3] = { pre_rate_filter_e1, pre_rate_filter_e2, pre_rate_filter_e3 };
float pre_filter_rate_1 = 0, pre_filter_rate_2 = 0, pre_filter_rate_3 = 0;
float pre_filter_rate[3] = { pre_filter_rate_1, pre_filter_rate_2, pre_filter_rate_3 };

//----------Position sampler
bool first_sample = true;
unsigned long sampler_start_time;
bool sampler_setup_flag;

//----------System setup
bool sys_ready = false;

//----------Read data from SD
// line buffer for 80 characters
char line[81];
bool setupFlag = true;
long SD_sampT = 6;
long SD_Timer;

//----------Latency----------------
unsigned long receive_time;
unsigned long latency;
unsigned long send_time_received;

//=======================================================
//======          Function Declaration            =======
//=======================================================
void recvWithStartEndMarkers(void);
void parseData(void);
void showParsedData(void);
void PIDupdate(float* target, int index, String mode);
void SerialPrintData(int type);
void SaveData2SD(String data);
void CheckCol(void);
void PosSampler(String mode);
void sendData(void);
void setPWMfrequency(void);

void setup() {
  //------------------------------Set system PSM frequency-----------------------------------
  setPWMfrequency();
  //-----------Set initial conditions----------------
  motor1.setSpeed(0);
  motor2.setSpeed(0);
  motor3.setSpeed(0);

  ref1 = false, ref2 = false, ref3 = false;
  ref_drive1 = false, ref_drive2 = false, ref_drive3 = false;

  //Attach pins to objects
  servos[0].attach(SERVO1);
  servos[1].attach(SERVO2);
  servos[2].attach(SERVO3);
  servos[3].attach(SERVO4);

  //-----------Start Communications-------------
  Serial.begin(115200);
  while (!Serial) {};
  Serial3.begin(115200);
  Serial.println("initialization done.");

  //-------------Define Pins--------------------------
  //Interruput pins
  pinMode(ENC1_A, INPUT_PULLUP);  // internal pullup input pin 2
  pinMode(ENC1_B, INPUT_PULLUP);  // internal pullup input pin 3
  pinMode(ENC2_A, INPUT_PULLUP);  // internal pullup input pin 18
  pinMode(ENC2_B, INPUT_PULLUP);  // internal pullup input pin 19
  pinMode(ENC3_A, INPUT_PULLUP);  // internal pullup input pin 20
  pinMode(ENC3_B, INPUT_PULLUP);  // internal pullup input pin 21

  //Limit switches
  pinMode(LS1_NC, INPUT_PULLUP);
  pinMode(LS1_NO, INPUT_PULLUP);
  pinMode(LS2_NC, INPUT_PULLUP);
  pinMode(LS2_NO, INPUT_PULLUP);
  pinMode(LS3_NC, INPUT_PULLUP);
  pinMode(LS3_NO, INPUT_PULLUP);

  //DC Motor driver
  pinMode(DC1_PWM, OUTPUT);
  pinMode(DC2_PWM, OUTPUT);
  pinMode(DC3_PWM, OUTPUT);
  pinMode(DC1_DIR, OUTPUT);
  pinMode(DC2_DIR, OUTPUT);
  pinMode(DC3_DIR, OUTPUT);

  //-----------------------------------------------------------------------------------------
  //---------------------------------System Referencen---------------------------------------
  //-----------------------------------------------------------------------------------------
  // -------------------------------------Home Servos----------------------------------------
  for (int i = 0; i < 4; i++) {
    servos[i].write(servo_off[i]);
    Serial.print(servo_off[i]);
    Serial.print('\t');
  }
  // -----------------------------Home Joint 1, 2 and 3--------------------------------------
  Enc1.write(0);
  Enc2.write(0);
  Enc3.write(0);
  if (refDevState == "auto") {  //Reference drive; Offset variables are determined automatically
    //-----------------------------------------------------------------------------------------
    //------------------------------Referenzfahrt Motor1---------------------------------------
    //-----------------------------------------------------------------------------------------
    Serial.println("Start Homing: Axis 1!");
    //Check pin status
    int pinstatusNC;
    int pinstatusNO;

    //Reference loop
    while (!ref1) {
      pinstatusNC = digitalRead(LS1_NC);  //If HIGH then button is pushed
      pinstatusNO = digitalRead(LS1_NO);  //If HIGH THEN button is not pushed

      //--------------------Check status-------------------------
      if (pinstatusNC == HIGH && pinstatusNO == LOW) {  //Touches Endposition
        motor1.setSpeed(0);
        Serial.println("Reached Limit Switch");
        state = reference;
        refpos1 = true;
        ref_drive1 = true;  //Indicates current reference drive
        dmg_cnt = 0;
      }

      else if (pinstatusNC == LOW && pinstatusNO == HIGH && !ref_drive1) {  //Does not touch endposition
        Serial.println("Initial sate: Not at limit switch");
        state = home;
        refpos1 = false;
        ref_drive1 = true;  //Indicates current reference drive
        dmg_cnt = 0;
      }

      else if ((pinstatusNC == LOW && pinstatusNO == LOW)) {
        dmg_cnt++;
        if (dmg_cnt >= 10) {
          motor1.setSpeed(0);
          Serial.print("Limit switch 1 is broken! Emergency stop!");
          ref_drive1 = false;  //Indicates current reference drive
          while (1) {};
        }
      }

      //---------------------Phase check-------------------------
      if (p_counter1 == 0) {
        speed1 = 25;
        pos1 = 15;
      } else if (p_counter1 == 1) {
        speed1 = 25;
        pos1 = 10;
      } else {
        speed1 = 5;
        pos1 = -5;
      }

      //--------------------State machine-----------------------
      // Case 0 ---> Home (Move to LS)
      // Case 1 ---> Retrieve (Move away from LS_
      // Case 2 ---> Reference
      switch (state) {

        case 0:  //HOME
          //Serial.println("Homing!");
          dir1 = 1;
          motor1.setSpeed(dir1 * speed1);
          if (pinstatusNC == HIGH && pinstatusNO == LOW) {  //Redundant check
            motor1.setSpeed(0);
            refpos1 = true;
            state = reference;
          }
          break;

        case 1:  //RETRIEVE
          dir1 = -1;
          motor1.setSpeed(dir1 * speed1);
          //Check for end position
          if (Ax1toAngle(Enc1.read()) >= pos1) {
            motor1.setSpeed(0);
            state = home;
            fixDelay(1000);
          }
          break;

        case 2:  //REFERENCE
          motor1.setSpeed(0);
          //Set reference or compare is phase!=0
          if (p_counter1 == 0 && refpos1 == true) {
            ref_counter1 = 0;
            Enc1.write(0);
            //counter1 = 0;
          } else if (p_counter1 > 0 && refpos1 == true) {
            int dif = abs(ref_counter1 - Enc1.read());
            if (dif <= threshold) {
              //Set counter to actual position
              Enc1.write(Ax1toCounts(ref_offset1));
              ref1 = true;
              ref_drive1 = false;
              Serial.print("Home! Position:");
              Serial.println(Enc1.read());
            } else {
              ref_counter1 = Enc1.read();
              Enc1.write(0);
            }
          }
          //Switch phase
          p_counter1++;
          //switch case
          state = retrieve;
          //Serial.println("1 second delay begin");
          fixDelay(1000);
          //Serial.println("1 second delay end");
          break;
      }
    }

    //-----------------------------------------------------------------------------------------
    //------------------------------Referenzfahrt Motor2---------------------------------------
    //-----------------------------------------------------------------------------------------
    Serial.println("Start Homing: Axis 2!");
    //Motor starting variables
    while (!ref2) {
      pinstatusNC = digitalRead(LS2_NC);  //If HIGH then button is pushed
      pinstatusNO = digitalRead(LS2_NO);  //If HIGH THEN button is not pushed

      //--------------------Check status-------------------------
      if (pinstatusNC == HIGH && pinstatusNO == LOW) {  //Touches Endposition
        motor2.setSpeed(0);
        //Serial.println("Reached Limit Switch");
        state = reference;
        refpos2 = true;
        ref_drive2 = true;  //Indicates current reference drive
      }

      else if (pinstatusNC == LOW && pinstatusNO == HIGH && !ref_drive2) {  //Does not touch endposition
        state = home;
        refpos2 = false;
        ref_drive2 = true;  //Indicates current reference drive
      }

      else if (pinstatusNC == LOW && pinstatusNO == LOW) {
        motor2.setSpeed(0);
        Serial.print("Limit switch 2 is broken! Emergency stop!");
      }

      //---------------------Phase check-------------------------
      if (p_counter2 == 0) {
        speed2 = 20;
        pos2 = -20;
      } else if (p_counter2 == 1) {
        speed2 = 20;
        pos2 = -10;
      } else {
        speed2 = 5;
        pos2 = -5;
      }

      //--------------------State machine-----------------------
      // This statemachine references the incremental encoder. A propper flow chart can be found in the Master Thesis in Appendix
      // Case 0 ---> Home (Move to LS)
      // Case 1 ---> Retrieve (Move away from LS_
      // Case 2 ---> Reference
      switch (state) {

        case 0:  //HOME
          //Serial.println("Homing!");
          dir2 = -1;
          motor2.setSpeed(dir2 * speed2);
          if (pinstatusNC == HIGH && pinstatusNO == LOW) {  //Redundant check
            motor2.setSpeed(0);
            refpos2 = true;
            state = reference;
          }
          break;

        case 1:  //RETRIEVE
          dir2 = 1;
          motor2.setSpeed(dir2 * speed2);
          //Check for end position
          if (Ax2toAngle(Enc2.read()) >= pos2) {
            motor2.setSpeed(0);
            state = home;
          }
          break;

        case 2:  //REFERENCE
          motor2.setSpeed(0);
          //Set reference or compare is phase!=0
          if (p_counter2 == 0 && refpos2 == true) {
            ref_counter2 = 0;
            Enc2.write(0);
          } else if (p_counter2 > 0 && refpos2 == true) {
            int dif = abs(ref_counter2 - Enc2.read());
            if (dif <= threshold) {
              //Set counter to actual position
              Enc2.write(Ax2toCounts(ref_offset2));
              ref2 = true;
              ref_drive2 = false;
              Serial.print("Homed Axis2!");
            } else {
              ref_counter2 = Enc2.read();
              Enc2.write(0);
            }
          }
          //Switch phase
          p_counter2++;
          //switch case
          state = retrieve;
          fixDelay(1000);
          break;
      }
    }
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
void loop() {
  if (sys_ready) {

    // Update control values of each motor; (Joint Space)
    //LPFilter_DT();

    //Extract data from string and update target position
    recvWithStartEndMarkers();
    while (newData == true) {
      receive_time = millis();
      strcpy(tempChars, receivedChars);
      // this temporary copy is necessary to protect the original data
      //   because strtok() used in parseData() replaces the commas with \0
      parseData();
      latency = receive_time - send_time_received;
      newData = false;
    }
    //showParsedData();

    // Limit target values
    target_pos1 = constrain(target_pos1, -15, 15);
    target_pos2 = constrain(target_pos2, -15, 15);
    target_pos3 = constrain(target_pos3, 40, 120);

    //Compute joint values of Endo-Wrist
    servo_val[0] = -target_pos4 / 1.4 + (servo_off[0] - 90);
    servo_val[1] = target_pos5 / 1.0 + (servo_off[1] - 90);
    servo_val[2] = (2 * target_pos6 - target_pos7 + 1.5 * servo_val[1]) / 2.0 + (servo_off[2] - 90);
    servo_val[3] = (target_pos7 / 1.0) + servo_val[2] + (servo_off[3] - 90);
    servo_val[0] = map(servo_val[0], -90, 90, 0, 180);
    servo_val[1] = map(servo_val[1], -90, 90, 0, 180);
    servo_val[2] = map(servo_val[2], -90, 90, 0, 180);
    servo_val[3] = map(servo_val[3], -90, 90, 0, 180);
    servo_val[0] = constrain(servo_val[0], 0, 180);
    servo_val[1] = constrain(servo_val[1], 0, 180);
    servo_val[2] = constrain(servo_val[2], 0, 180);
    servo_val[3] = constrain(servo_val[3], 0, 180);

    // Update desired position for joints 1, 2 and 3
    getDT();
    for (int i = 0; i < 3; i++) {
      PIDupdate(target_pos[i], i, c_mode);
    }

    //Update servo motors
    for (int i = 0; i < 4; i++) {
      int val = servo_val[i];
      servos[i].write(val);
    }

    //Compute x,y,z position (forward kinematics)
    q[0] = Ax1toAngle(Enc1.read()) * PI / 180;  //convert to rad
    q[1] = Ax2toAngle(Enc2.read()) * PI / 180;  //convert to rad
    q[2] = Ax3toAngle(Enc3.read());
    x = -cos(q[1] - PI / 2) * (q[2] + d0);
    y = cos(q[0]) * sin(q[1] - PI / 2) * (q[2] + d0);
    z = -sin(q[0]) * sin(q[1] - PI / 2) * (q[2] + d0);

    // Debugging
    SerialPrintData(14);
  }
}

//-----------------------------------------------------------------------------------------
//-------------------------------------FUNCTIONS-------------------------------------------
//-----------------------------------------------------------------------------------------
String compData(double in_value1, double in_value2, double in_value3, byte signi) {
  char buffer[20];
  String serialData;

  dtostrf(in_value1, 0, 2, buffer);
  serialData = "<";
  serialData += buffer;
  serialData += ",";
  dtostrf(in_value2, 0, 2, buffer);
  serialData += buffer;
  serialData += ",";
  dtostrf(in_value3, 0, 2, buffer);
  serialData += buffer;
  serialData += ">";

  return serialData;
}

void fixDelay(uint32_t ms) {
  delay(ms);
}

void getDT(void) {
  //Only call once in routine
  currT = micros();
  dt = (currT - prevT) / 1.0e6;
  prevT = currT;
}

void sendData(void) {
  Serial.print(*target_pos[0], 4);
  Serial.print('/');
  Serial.print(*target_pos[1], 4);
  Serial.print('/');
  Serial.print(*target_pos[2], 4);
  Serial.print('/');
  Serial.print(Ax1toAngle(Enc1.read()), 4);
  Serial.print('/');
  Serial.print(Ax2toAngle(Enc2.read()), 4);
  Serial.print('/');
  Serial.print(Ax3toAngle(Enc3.read()), 4);
  Serial.print('/');
  Serial.print(prev_e[0], 4);
  Serial.print('/');
  Serial.print(prev_e[1], 4);
  Serial.print('/');
  Serial.print(prev_e[2], 4);
  Serial.print('/');
  Serial.print(m_speed[0]);
  Serial.print('/');
  Serial.print(m_speed[1]);
  Serial.print('/');
  Serial.println(m_speed[2]);
}

float Ax1toAngle(long count) {
  float q;
  float trans = 20.000;
  q = (-1) * (float)count * res_avago / trans;
  return q;
}

float Ax2toAngle(long count) {
  float q;
  float trans = 13.333;
  q = (-1) * (float)count * res_avago / trans;
  return q;
}

float Ax3toAngle(long count) {
  float q;
  //float trans = 0.637;
  float D = 19.10;
  float pi = 3.1416;
  float ref = 360;
  q = (1) * pi * D * (float)count * res_avago / ref;
  return q;
}

int Ax1toCounts(float angle) {
  int q;
  float trans = 20.000;
  q = int(-1.0 * angle * trans / res_avago);
  return q;
}

int Ax2toCounts(float angle) {
  int q;
  float trans = 13.333;
  q = int(-1.0 * angle * trans / res_avago);
  return q;
}

int Ax3toCounts(float pos) {
  int q;
  //float trans = 0.637;
  float D = 19.10;
  float ref = 360;
  q = int(1.0 * (pos * ref) / (PI * D * res_avago));
  return q;
}

void readJointValues() {
  Serial.flush();
  while (Serial.available() == 0) {}
  String t = Serial.readString();
  t.trim();

  //Fill array
}


// ATOMIC_BLOCK(ATOMIC_RESTORESTATE) {
//   currCount[0] = counter1;
//   currCount[1] = counter2;
//   currCount[2] = counter3;
// }

// // for (int i = 0; i < sizeof(vel) / sizeof(vel[0]); i++) {
// //   vel[i] = (currCount[i] - preCount[i])/deltaT;
// //   preCount[i] = currCount[i];
// // }

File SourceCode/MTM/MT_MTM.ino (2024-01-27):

//=======================================================
//======            Include libraries             =======
//=======================================================

//#include <avr/wdt.h>  //Watchdog Timer Library
#include "I2Cdev.h"
#include "MPU6050_6Axis_MotionApps20.h"
//#include "MPU6050.h"
#include <helper_3dmath.h>
#include <stdfix.h>
#include <math.h>
#include <SoftwareSerial.h>
#include <string.h>


#if I2CDEV_IMPLEMENTATION == I2CDEV_ARDUINO_WIRE
#include "Wire.h"
#endif

//=======================================================
//======     Define RUN, DEBUG, EVALUATION        =======
//=======================================================
//#define RUN
//#define DEBUG
#define EVAL

//=======================================================
//======    Define DMP or Complement filter       =======
//=======================================================
#define DMP
//#define COMP

//=======================================================
//======                 Makros                   =======
//=======================================================
// Defina I2C address
#define ADR 0  //Order for Read out and Setup
#define ADL 1  //

//Define Pins
#define RESET 14  // Responsible for RESET
#define DO1R 2    // Encoder Shoulder Pitch right
#define DO2R 3    // Encoder Shoulder Yaw right
#define DO3R 4    // Encoder Elbow right
#define DO1L 5    // Encoder Shoulder Pitch left
#define DO2L 6    // Encoder Shoulder Yaw left
#define DO3L 7    // Encoder Elbow left

#define CS1R 8   // Chip Select right
#define CS2R 9   // %
#define CS3R 10  // %
#define CS1L 11  // Chip select left
#define CS2L 12  // %
#define CS3L 13  // %

#define AD0R 29  // IMU Address right
#define AD0L 30  // IMU Address left

#define CLKR 44  // Clock signal right
#define CLKL 46  // Clock signal left

#define HDOR 0  // Analog Input 0 (Hall Sensor)
#define HDOL 1

#define MPU_ADDR_R 0x68
#define MPU_ADDR_L 0x69

//Define Calibration Values for IMU left in horizontal position
#define MPU6050L_ACCEL_OFFSET_X -788
#define MPU6050L_ACCEL_OFFSET_Y 1417
#define MPU6050L_ACCEL_OFFSET_Z 998
#define MPU6050L_GYRO_OFFSET_X 37
#define MPU6050L_GYRO_OFFSET_Y -14
#define MPU6050L_GYRO_OFFSET_Z 40

// -------------------------Calibration in horizontal-----------------------------
//Define Calibration Values for IMU right in horizontal position
#define MPU6050R_ACCEL_OFFSET_X -818
#define MPU6050R_ACCEL_OFFSET_Y 1453
#define MPU6050R_ACCEL_OFFSET_Z 992
#define MPU6050R_GYRO_OFFSET_X 33
#define MPU6050R_GYRO_OFFSET_Y -12
#define MPU6050R_GYRO_OFFSET_Z 37


// Math constants
#define PI 3.1415926535897932384626433832795

//=======================================================
//======             GLOBAL VARIABLES             =======
//=======================================================
/*--------Causes a Null Operation which has no effect-----*/
#define DELAY_CYCLES(n) __builtin_avr_delay_cycles(n)  //Skips n ticks. delay = n*62.5ns /n is integer
unsigned int const delay_375ns = 6;
unsigned int const delay_500ns = 8;

/*-------------------MPU control/status vars--------------*/
bool dmpReady;  // set true if DMP init was successful
bool IMUready;
uint8_t devStatus;       // return status after each device operation (0 = success, !0 = error)
uint16_t packetSize;     // expected DMP packet size (default is 42 bytes)
uint16_t fifoCount;      // count of all bytes currently in FIFO
uint8_t fifoBuffer[64];  // FIFO storage buffer

/*---------------------create IMU Object------------------*/
MPU6050 mpuR(0x68);
MPU6050 mpuL(0x69);
MPU6050 mpu[] = { mpuR, mpuL };

/*-------------------Serial Communication-----------------*/
//SoftwareSerial SUART(0, 1);

/*-------------------OFFSET Encoder values----------------*/
float const Enc1R_OFF = 1684;  //1684;
float const Enc2R_OFF = 2350;  //2353; new 2350
float const Enc3R_OFF = 1790;  //1823; new 1832
float EncR_OFF[3] = { Enc1R_OFF, Enc2R_OFF, Enc3R_OFF };

float const Enc1L_OFF = 526;
float const Enc2L_OFF = 1355;
float const Enc3L_OFF = 3109;
float EncL_OFF[3] = { Enc1L_OFF, Enc2L_OFF, Enc3L_OFF };

/*--------------------OVERFLOW detection------------------*/
int temp_side = 0;
int const high_lim = 2047;
int const low_lim = -2048;
int const gain = 4095;
int countR1 = 0, countR2 = 0, countR3 = 0;
int *countR[3] = { &countR1, &countR2, &countR3 };
int countL1 = 0, countL2 = 0, countL3 = 0;
int *countL[3] = { &countL1, &countL2, &countL3 };
bool rolloverR1 = false, rolloverR2 = false, rolloverR3 = false;
bool rolloverL1 = false, rolloverL2 = false, rolloverL3 = false;
bool rollunderR1 = false, rollunderR2 = false, rollunderR3 = false;
bool rollunderL1 = false, rollunderL2 = false, rollunderL3 = false;
bool *rolloverR[3] = { &rolloverR1, &rolloverR2, &rolloverR3 };
bool *rolloverL[3] = { &rolloverL1, &rolloverL2, &rolloverL3 };
bool *rollunderR[3] = { &rollunderR1, &rollunderR2, &rollunderR3 };
bool *rollunderL[3] = { &rollunderL1, &rollunderL2, &rollunderL3 };

int Enc1R_inc, Enc2R_inc, Enc3R_inc;
int Enc1L_inc, Enc2L_inc, Enc3L_inc;
int *EncDataR_inc[3] = { &Enc1R_inc, &Enc2R_inc, &Enc3R_inc };
int *EncDataL_inc[3] = { &Enc1L_inc, &Enc2L_inc, &Enc3L_inc };

/*-----------------------Orientation and motion vars-------------------------*/
//Quaternion array --> q = [w, x, y, z]
Quaternion qR, qL;  //current raw quaternion container; left / right IMU
Quaternion *q[2] = { &qR, &qL };
Quaternion pR = { 0.7044, -0.0001, -0.7098, -0.0027 }, pL = { 1, 0, 0, 0 };
Quaternion p[2] = { pR, pL };
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

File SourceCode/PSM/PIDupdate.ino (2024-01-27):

/*PIDupdate --> Geneartion of control values for axes 1-3;
Update routine that is called once per cycle to update the control values of each axis based on the target value
which is handed over.
Input Arguments:
  -target: Desired Position (is received over UART)
  -index: incrementing value that indicates the axis of interest.
  -Mode: Allows to select between 'P', 'PI', 'PD' and 'PID' controller
In addition the function features integrator clamping to avoid effects of integrator windup.
*/
void PIDupdate(float* target, int index, String mode) {
  //Function variables
  float current;
  float kp, ki, kd;
  int PID_select;
  float u;
  float Umag;
  double rate;
  int sign_e;
  int sign_u;
  float clamp_Lim_up;
  float clamp_Lim_low;
  int dir;
  int speed;

  // Select mode of controller ("P","PI","PD" or "PID")
  if (mode == "P") {
    PID_select = 0;
  } else if (mode == "PI") {
    PID_select = 1;
  } else if (mode == "PD") {
    PID_select = 2;
  } else if (mode == "PID") {
    PID_select = 3;
  } else {
    PID_select = 0;
  }  //DEFAULT

  //Choose parameters based on index
  switch (index) {
    case 0:
      current = Ax1toAngle(Enc1.read());
      kp = 35, ki = 50, kd = 5;  //5
      clamp_Lim_up = 32;
      clamp_Lim_low = -32;
      Umag = 15.0;
      break;
    case 1:
      current = Ax2toAngle(Enc2.read());
      kp = 60, ki = 110, kd = 5;  //40
      Umag = 15.0;
      clamp_Lim_up = 40;
      clamp_Lim_low = -40;
      break;
    case 2:
      current = Ax3toAngle(Enc3.read());
      kp = 45, ki = 800, kd = 3.8;  //3.8
      Umag = 7.4;
      clamp_Lim_up = 7;
      clamp_Lim_low = -7;
      break;
    default:
      kp = 0, ki = 0, kd = 0;
      Umag = 1;
      break;
  }

  //---------------------Controller---------------
  float e = *target - current;
  //----Derivative
  rate = (e - prev_e[index]) / dt;
  rate_e[index] = rate;
  //----LP-filter
  rate = 0.956 * pre_rate_filter[index] + 0.0245 * rate_e[index] + 0.0245 * prev_rate_e[index];

  //PID controlelr state machine
  switch (PID_select) {
    case 0:  //P-mode
      u = kp * e;
      break;

    case 1:  //PI-mode
      if (!clamp_I[index]) {
        // Integrator
        integral[index] += e * dt;
        u = kp * e + ki * integral[index];
      } else if (clamp_I[index]) {
        u = kp * e;
      }
      break;

    case 2:  //PD-mode
      u = kp * e + kd * rate;
      break;

    case 3:  //PID-mode (To-Do: NOT WORKING)
      if (!clamp_I[index]) {
        // Integrator
        integral[index] += e * dt;
        u = kp * e + ki * integral[index] + kd * rate;
      } else if (clamp_I[index]) {
        u = kp * e + kd * rate;
      }
      break;
  }

  //Update LP filter values for rate
  pre_rate_filter[index] = rate;
  prev_rate_e[index] = rate_e[index];
  //Update previous error
  prev_e[index] = e;

  // Check if clamping is requried
  control_values[index] = u;
  sat_control_values[index] = constrain(u, clamp_Lim_low, clamp_Lim_up);  //Dont clamp at physical limit of motor; Prevents remaining Windup!
  if (u < 0) {
    sign_u = -1;
  } else {
    sign_u = 1;
  }
  if (e < 0) {
    sign_e = -1;
  } else {
    sign_e = 1;
  }
  if ((sign_u == sign_e) && (control_values[index] != sat_control_values[index])) {
    clamp_I[index] = true;
  } else {
    clamp_I[index] = false;
  }

  //Determine direction
  dir = -1;
  if (u < 0) {
    dir = 1;
  }
  //Determine speed
  speed = (int)fabs(u);
  if (speed > 255) {
    speed = 255;
  }

  if((speed < 8) && (index == 2)){
    speed = 8;
  }
  
  m_speed[index] = dir * speed; //For Evaluation

  motor[index].setSpeed(dir * speed);
}
